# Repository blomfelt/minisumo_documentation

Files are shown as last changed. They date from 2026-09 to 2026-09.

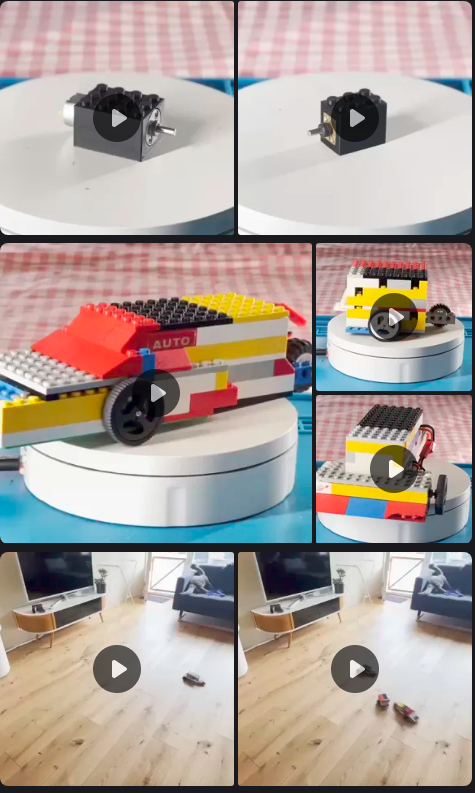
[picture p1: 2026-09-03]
img/lego concept från john till pg via discord 260510.png

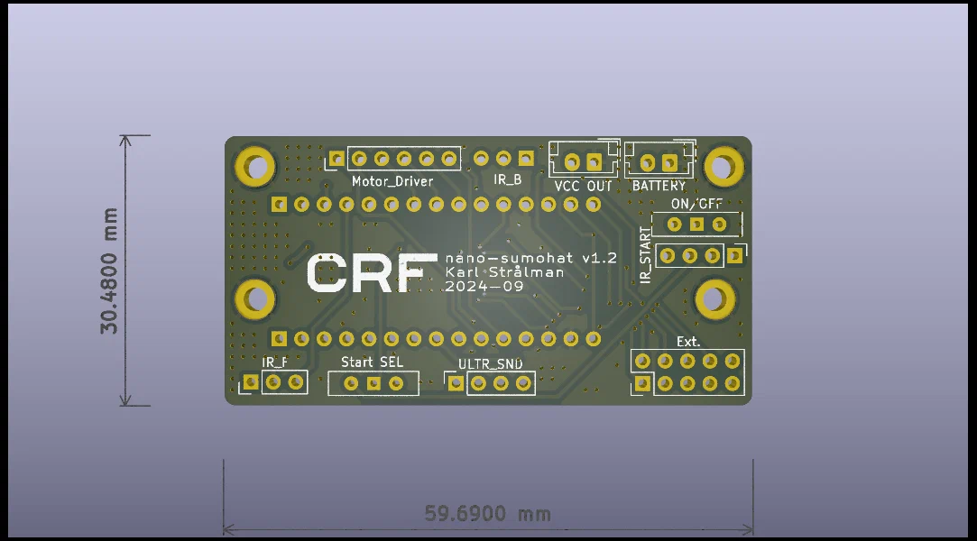
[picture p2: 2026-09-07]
documentation/resources/_gen/images/images/pcb_hu_88633c255bfc3661.webp

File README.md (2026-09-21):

# CRF minisumo++2027 (CRFminisumoplusplus2027)

A follow-up to the [CRF SumoBot](https://github.com/ChalmersRobotics/CRF-SumoBot)[^1] designed primarily by Kalle Strålman and David Strålman.

After RobotSM 2026 we sold out of kits that were arduino based and ran out of batteries that were cheap. While doing these changes we also chose to update the PCB and make some pretty big changes to the model, so why not make upgrades!?

## Concept for minisumo++2027
A minisumo .. plus some other things .. plus even some more!
- Minisumo for robotSM primarily, but as possible a module that can be a spring board into other things
- Minisumo that one steers like an RC car via bluetooth!
- Lego version! .. encapsulate motors and such into a robot combat like (or autonomous robot?) that can be lego'd together!
- [Death racers](https://www.youtube.com/watch?v=i10rxmsKHts)
- Robot combat base module
- More? Why not?? Probably possible
  - Line following!?
  - Esphome controlled robot w/ or w/o home assistant!?

## Goals and features
1. Good for beginners to meet the primary goal of minisumo for robotSM
2. Cheap as chips
3. Possibility to make really really smallish, for example to encapsulate into lego!
4. More voltage to motors!
5. Battery charging possible since using the c6!
6. Possibility to expand and reuse gpio's or other purpose robots!

## TODO
- [x] Choose wires or PCB for connection (PCB right now)
- [x] Add sensors
- [x] Add Sumo-code
- [x] Add bluetooth code
- [x] Control motors via bluetooth
- [ ] Design the chassis
- [ ] Write build instructions
- [ ] PCBs - need to build to confirm eg ALL footprints (all done by hand) && perform functional tests with everything mounted as designed with software running && confirm within eventual 3d packaging.

## Instructions
- Obtain Components and Chassis (See *Bill of Materials below*) or via a kit @ CRF while supplies last!
- Download the `minisumo-bot.ino` file from [releases on the right side](https://github.com/ChalmersRobotics/minisumoplusplus2027/releases)
- Build the robot according to the [instructions](TODO)
- Upload the code to the robot as in the [instructions](TODO) or as documented below.

### Instructions for pcb assembly / soldering incl tips and tricks
tbd

### Instructions for final assembly
tbd

### Instructions for uploading code to the ESP32
- Install Arduino IDE v2 from their [website](https://docs.arduino.cc/software/ide-v2/tutorials/getting-started/ide-v2-downloading-and-installing/)[^2] or your favourite package manager. Current version is 2.3.10.
- Install the required boards from the Boards Manager in the left column, second icon from the top:
    - esp32 by Espressif Systems (current version 3.3.11)
- Install the required libraries from the Library Manager, icon under the Boards Manager (or via Tools > Manage Libraries):
    - "NimBLE_Arduino" by h2zero (current version 2.5.1)
    - "HCSR04" by Martin Sosic (current version 2.0.0)
- Choose the correct board from the Select Board dropdown > Select other board and port. Then Search for *MakerGO ESP32 C6 SuperMini*. It will look as if nothing happens but that is fine.
- Connect the ESP32 to your computer while holding the BOOT button on the board. It will show up in the right column as something like `/dev/usb/ttyASM0` if you are on linux. Click Ok.
    - The board may not show up, in which case you need to hold the Boot button while connecting the board, then tapping the RST button and finally releasing the BOOT button.
- Paste the contents of `minisumo-bot.ino` into the default sketch or download the file and open it from File > Open
- Verify and/or Upload the sketch to the ESP32 using the checkbox and/or arrow in the top left corner.

### Bill of Materials
See [the google sheets bom](https://docs.google.com/spreadsheets/d/1KNLTKy2cLUtDrH-E30Gfz_4ahhQaqS2SGsFHG1Fw9_M/edit?usp=sharing))
- PCB
- 3D printed chassis
- [ESP32 C6 Super Mini](https://mischianti.org/esp32-c6-supermini-high-resolution-pinout-datasheet-schema-and-specs/)
- Battery 3.7v cr123 with recharge usb c contact built in!
- Battery contacts!
- Buck boost to push motor driver to 9v!
- Switch on / off .. a smaller one is needed
- Motor driver: L298N
- Ultrasonic sensor: HC-SR04
- IR sensor: v183
- Start module
- Cables

## Changelog

| Version | Changes |
| --- | --- |
| v1.0 | First draft |

## References
[^1]: CRF SumoBot, Kalle Strålman, [https://github.com/ChalmersRobotics/CRF-SumoBot](https://github.com/ChalmersRobotics/CRF-SumoBot)
[^2]: Downloading and installing the Arduino IDE 2, Arduino, [https://docs.arduino.cc/software/ide-v2/tutorials/getting-started/ide-v2-downloading-and-installing/](https://docs.arduino.cc/software/ide-v2/tutorials/getting-started/ide-v2-downloading-and-installing/)

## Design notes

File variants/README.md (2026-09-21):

The home of every variant of the minisumoplusplus bot. 

Each variant get their own folder, which contain both the code and any neccessary 3d-printing files.

Symlinks to other folders are permitted, if they for example use the same chassis as another bot.
A symlink is created in linux / WSL using the `ln -s source_file symbolic_link` command.

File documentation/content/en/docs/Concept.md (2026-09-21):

---
weight: 1
title: "Concept"
description: ""
icon: "article"
date: "2026-09-21T15:22:42+02:00"
lastmod: "2026-09-21T15:22:42+02:00"
draft: false
toc: true
---

A follow-up to the [CRF SumoBot](https://github.com/ChalmersRobotics/CRF-SumoBot)[^1] designed primarily by Kalle Strålman and David Strålman.

After RobotSM 2026 we sold out of kits that were arduino based and ran out of batteries that were cheap. While doing these changes we also chose to update the PCB and make some pretty big changes to the model, so why not make upgrades!?

## Concept for minisumo++2027
A minisumo .. plus some other things .. plus even some more!
- Minisumo for robotSM primarily, but as possible a module that can be a spring board into other things
- Minisumo that one steers like an RC car via bluetooth!
- Lego version! .. encapsulate motors and such into a robot combat like (or autonomous robot?) that can be lego'd together!
- [Death racers](https://www.youtube.com/watch?v=i10rxmsKHts)
- Robot combat base module
- More? Why not?? Probably possible
  - Line following!?
  - Esphome controlled robot w/ or w/o home assistant!?

## Goals and features
1. Good for beginners to meet the primary goal of minisumo for robotSM
2. Cheap as chips
3. Possibility to make really really smallish, for example to encapsulate into lego!
4. More voltage to motors!
5. Battery charging possible since using the c6!
6. Possibility to expand and reuse gpio's or other purpose robots!

## Variants
A minisumo .. plus some other things .. plus even some more!

- [Minisumo for robotSM](https://www.robotsm.se/competitions-and-rules/#:~:text=Sumo,-In) primarily, but as possible a module that can be a spring board into other things
- Minisumo that one steers like an RC car via bluetooth!
- Lego version! .. encapsulate motors and such into a robot combat like (or autonomous robot?) that can be lego'd together!
- Death racers: [video example](https://www.youtube.com/watch?v=i10rxmsKHts) and [official page](https://rockymountainreprapfestival.com/competitions/)
- [Robot combat](https://www.robotsm.se/competitions-and-rules/#:~:text=Robot%20combat) base module
- More? Why not?? Probably possible
    - [Line following](https://www.robotsm.se/competitions-and-rules/#:~:text=Line%20following)!?
    - Esphome controlled robot w/ or w/o home assistant!?

## References
[^1]: CRF SumoBot, Kalle Strålman, [https://github.com/ChalmersRobotics/CRF-SumoBot](https://github.com/ChalmersRobotics/CRF-SumoBot)

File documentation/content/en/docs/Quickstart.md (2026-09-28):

---
weight: 2
title: "Quickstart (minisumo)"
description: ""
icon: "star"
date: "2026-09-01T21:43:11+02:00"
lastmod: "2026-09-01T21:43:11+02:00"
draft: false
toc: true
---

Det finns även svensk version av instruktionerna, du kan byta språk längst upp till höger under **EN**, eller genom att [klicka här](/minisumo_documentation/sv/docs/).

- Obtain Components and Chassis (See [Bill of Materials](/docs/step_by_step/bom.md)) by buying a kit from us at CRF or by providing your own.
- Download the `minisumo-bot.ino` file from [the minisumo-bot folder on github](https://github.com/ChalmersRobotics/minisumoplusplus2027/blob/main/variants/minisumo-bot/minisumo-bot.ino)
- Build the robot according to the [instructions](/docs/step_by_step/)
- Upload the code to the robot as [described here](/docs/step_by_step/programming/).

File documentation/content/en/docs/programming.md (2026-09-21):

---
weight: 200
title: "Programming an ESP32"
description: ""
icon: "upload"
date: "2026-09-01T21:49:12+02:00"
lastmod: "2026-09-01T21:49:12+02:00"
draft: false
toc: true
---

- Install Arduino IDE v2 from their [website](https://docs.arduino.cc/software/ide-v2/tutorials/getting-started/ide-v2-downloading-and-installing/)[^3] or your favourite package manager. Current version is 2.3.8.
- Install the required boards from the Boards Manager in the left column, second icon from the top:
    - esp32 by Espressif Systems (current version 3.3.11)
- Install the required libraries from the Library Manager, icon under the Boards Manager (or via Tools > Manage Libraries):
    - "HCSR04" by Martin Sosic (current version 2.0.0)
    - If you are going to remote control it using bluetooth: "NimBLE_Arduino" by h2zero (current version 2.5.1)
- Choose the correct board from the Select Board dropdown > Select other board and port. Then Search for *MakerGO ESP32 C6 SuperMini*. It will look as if nothing happens but that is fine.
- Connect the ESP32 to your computer while holding the BOOT button on the board. It will show up in the right column as something like `/dev/usb/ttyASM0` if you are on linux. Click Ok.
    - The board may not show up, in which case you need to hold the Boot button while connecting the board, then tapping the RST button and finally releasing the BOOT button.
- Paste the contents of `minisumo-bot.ino` into the default sketch or download the file and open it from File > Open
- If you want to see the serial monitor when the ESP is connected to your computer you need to enable "*USB CDC On Boot*" under Tools in the top bar, after which you can open the Serial Monitor in the top right corner under the magnifying glass.
- Verify and/or Upload the sketch to the ESP32 using the checkbox and/or arrow in the top left corner.
- **Done!** Now it will run the code you uploaded to it every time it is powered on!

[^3]: Downloading and installing the Arduino IDE 2, Arduino, [https://docs.arduino.cc/software/ide-v2/tutorials/getting-started/ide-v2-downloading-and-installing/](https://docs.arduino.cc/software/ide-v2/tutorials/getting-started/ide-v2-downloading-and-installing/)

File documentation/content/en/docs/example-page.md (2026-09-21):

---
weight: 999
title: "CRF Minisumo bot"
description: ""
icon: "info"
date: "2026-09-01T19:05:21+02:00"
lastmod: "2026-09-01T19:05:21+02:00"
draft: true
toc: true
---

A follow-up to the [CRF SumoBot](https://github.com/ChalmersRobotics/CRF-SumoBot)[^1] designed by Kalle Strålman.

Bluetooth remote control code from Shib Sankar Das's [ESP32-Bluetooth-RC-Car-Project](https://github.com/Shib-Sankar-Das/ESP32-Bluetooth-RC-Car-Project/)[^2]

Please find:
- [Instructions and workshop intro (v1.2, updated 251105) - here](TODO)
- [3D manufacturing files](TODO)
- [complete release package - here!](https://github.com/ChalmersRobotics/CRF-SumoBot/releases)

"Rendered image of nano-hat v1.2"

## TODO
- [x] Choose wires or PCB for connection (PCB right now)
- [x] Add sensors
- [x] Add Sumo-code
- [ ] Design the chassis
- [ ] Write build instructions

## Instructions
- Obtain Components and Chassis (See *Bill of Materials below*)
- Download the `minisumo-bot.ino` file from [releases on the right side](https://github.com/ChalmersRobotics/CRF-SumoBot/releases)
- Build the robot according to the [instructions](TODO)
- Upload the code to the robot as in the [instructions](TODO) or as documented below.

## Uploading code to the ESP32
- Install Arduino IDE v2 from their [website](https://docs.arduino.cc/software/ide-v2/tutorials/getting-started/ide-v2-downloading-and-installing/)[^3] or your favourite package manager. Current version is 2.3.8.
- Install the required boards from the Boards Manager in the left column, second icon from the top:
    - esp32 by Espressif Systems (current version 3.3.11)
- Install the required libraries from the Library Manager, icon under the Boards Manager (or via Tools > Manage Libraries):
    - "NimBLE_Arduino" by h2zero (current version 2.5.1)
    - "HCSR04" by Martin Sosic (current version 2.0.0)
- Choose the correct board from the Select Board dropdown > Select other board and port. Then Search for *MakerGO ESP32 C6 SuperMini*. It will look as if nothing happens but that is fine.
- Connect the ESP32 to your computer while holding the BOOT button on the board. It will show up in the right column as something like `/dev/usb/ttyASM0` if you are on linux. Click Ok.
    - The board may not show up, in which case you need to hold the Boot button while connecting the board, then tapping the RST button and finally releasing the BOOT button.
- Paste the contents of `minisumo-bot.ino` into the default sketch or download the file and open it from File > Open
- Verify and/or Upload the sketch to the ESP32 using the checkbox and/or arrow in the top left corner.

## Bill of Materials
- PCB
- 3D printed chassis
- ESP32 C6 Supermini
- Motor driver: L298N
- Ultrasonic sensor: HC-SR04
- IR sensor: v183
- Cables

## Changelog

| Version | Changes |
| --- | --- |
| v1.0 | First draft |

## References
[^1]: CRF SumoBot, Kalle Strålman, [https://github.com/ChalmersRobotics/CRF-SumoBot](https://github.com/ChalmersRobotics/CRF-SumoBot)
[^2]: ESP32-Bluetooth-RC-Car-Project, Shib Sankar Das, [https://github.com/Shib-Sankar-Das/ESP32-Bluetooth-RC-Car-Project/](https://github.com/Shib-SankAar-Das/ESP32-Bluetooth-RC-Car-Project/)
[^3]: Downloading and installing the Arduino IDE 2, Arduino, [https://docs.arduino.cc/software/ide-v2/tutorials/getting-started/ide-v2-downloading-and-installing/](https://docs.arduino.cc/software/ide-v2/tutorials/getting-started/ide-v2-downloading-and-installing/)

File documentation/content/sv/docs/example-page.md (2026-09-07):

---
weight: 2
title: "CRF Minisumo bot"
description: ""
icon: "article"
date: "2026-09-01T19:05:21+02:00"
lastmod: "2026-09-01T19:05:21+02:00"
draft: false
toc: true
---

A follow-up to the [CRF SumoBot](https://github.com/ChalmersRobotics/CRF-SumoBot)[^1] designed by Kalle Strålman.

Bluetooth remote control code from Shib Sankar Das's [ESP32-Bluetooth-RC-Car-Project](https://github.com/Shib-Sankar-Das/ESP32-Bluetooth-RC-Car-Project/)[^2]

Please find:
- [Instructions and workshop intro (v1.2, updated 251105) - here](TODO)
- [3D manufacturing files](TODO)
- [complete release package - here!](https://github.com/ChalmersRobotics/CRF-SumoBot/releases)

"Rendered image of nano-hat v1.2"

## TODO
- [x] Choose wires or PCB for connection (PCB right now)
- [x] Add sensors
- [x] Add Sumo-code
- [ ] Design the chassis
- [ ] Write build instructions

## Instructions
- Obtain Components and Chassis (See *Bill of Materials below*)
- Download the `minisumo-bot.ino` file from [releases on the right side](https://github.com/ChalmersRobotics/CRF-SumoBot/releases)
- Build the robot according to the [instructions](TODO)
- Upload the code to the robot as in the [instructions](TODO) or as documented below.

## Uploading code to the ESP32
- Install Arduino IDE v2 from their [website](https://docs.arduino.cc/software/ide-v2/tutorials/getting-started/ide-v2-downloading-and-installing/)[^3] or your favourite package manager. Current version is 2.3.8.
- Install the required boards from the Boards Manager in the left column, second icon from the top:
    - esp32 by Espressif Systems (current version 3.3.11)
- Install the required libraries from the Library Manager, icon under the Boards Manager (or via Tools > Manage Libraries):
    - "NimBLE_Arduino" by h2zero (current version 2.5.1)
    - "HCSR04" by Martin Sosic (current version 2.0.0)
- Choose the correct board from the Select Board dropdown > Select other board and port. Then Search for *MakerGO ESP32 C6 SuperMini*. It will look as if nothing happens but that is fine.
- Connect the ESP32 to your computer while holding the BOOT button on the board. It will show up in the right column as something like `/dev/usb/ttyASM0` if you are on linux. Click Ok.
    - The board may not show up, in which case you need to hold the Boot button while connecting the board, then tapping the RST button and finally releasing the BOOT button.
- Paste the contents of `minisumo-bot.ino` into the default sketch or download the file and open it from File > Open
- Verify and/or Upload the sketch to the ESP32 using the checkbox and/or arrow in the top left corner.

## Bill of Materials
- PCB
- 3D printed chassis
- ESP32 C6 Supermini
- Motor driver: L298N
- Ultrasonic sensor: HC-SR04
- IR sensor: v183
- Cables

## Changelog

| Version | Changes |
| --- | --- |
| v2.0 | <ul><li>Updated PCB design</li><li>Changed to ESP from Arduino</li></ul> |
| v1.2 | <ul><li>Add EN_A and EN_B pins for controlling H-Bridge speed</li><li>Move start module placement slightly more towards the edge</li><li>Add header pins for unused ports on the Arduino to allow further extension / mods</li>Add an optional switch to pull-up and bypass start module</ul> |
| v1.1 | <ul><li>Move mounting holes slightly</li><li>Add header pins for start module</li></ul> |
| v1.0 | First draft |

## References
[^1]: CRF SumoBot, Kalle Strålman, [https://github.com/ChalmersRobotics/CRF-SumoBot](https://github.com/ChalmersRobotics/CRF-SumoBot)
[^2]: ESP32-Bluetooth-RC-Car-Project, Shib Sankar Das, [https://github.com/Shib-Sankar-Das/ESP32-Bluetooth-RC-Car-Project/](https://github.com/Shib-SankAar-Das/ESP32-Bluetooth-RC-Car-Project/)
[^3]: Downloading and installing the Arduino IDE 2, Arduino, [https://docs.arduino.cc/software/ide-v2/tutorials/getting-started/ide-v2-downloading-and-installing/](https://docs.arduino.cc/software/ide-v2/tutorials/getting-started/ide-v2-downloading-and-installing/)

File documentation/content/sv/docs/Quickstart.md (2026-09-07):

---
weight: 1
title: "Quickstart"
description: ""
icon: "article"
date: "2026-09-01T21:43:11+02:00"
lastmod: "2026-09-01T21:43:11+02:00"
draft: false
toc: true
---

- Obtain Components and Chassis (See [Bill of Materials](/docs/step_by_step/bom.md))
- Download the `minisumo-bot.ino` file from [releases on the right side](https://github.com/ChalmersRobotics/CRF-SumoBot/releases)
- Build the robot according to the [instructions](TODO)
- Upload the code to the robot as in the [instructions](TODO) or as [described here](/docs/step_by_step/programming/).

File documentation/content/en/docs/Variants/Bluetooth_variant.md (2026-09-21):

---
weight: 12
title: "Bluetooth"
description: ""
icon: "article"
date: "2026-09-21T14:24:28+02:00"
lastmod: "2026-09-21T14:24:28+02:00"
draft: false
toc: true
---

The bluetooth variant of the sumobot uses Bluetooth Low Energy (BLE) to communicate with for example an app on your phone. 

If you are using android you can use the app [BLE Joystick](https://play.google.com/store/apps/details?id=iyok.com.blejoystickpro) to control the robot.

For debugging the characteristics you can use the app [nRF Connect](https://play.google.com/store/apps/details?id=no.nordicsemi.android.mcp).

For this bot there are not complete build instructions, but the info found in the [quickstart guide for the minisumo bot](/docs/quickstart) and the [full build instructions for the minisumo bot]() applies, except that you don't need the IR sensors or Ultrasonic distance sensors, however you can add them to the bot and modify the code to include them if you want!

The code is located at [variants/Bluetooth_control/Bluetooth_control.ino](https://github.com/ChalmersRobotics/minisumoplusplus2027/blob/main/variants/Bluetooth_control/Bluetooth_control.ino) in the GitHub.

The 3D-printing files are located at [this link](link)

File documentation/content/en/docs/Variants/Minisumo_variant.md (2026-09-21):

---
weight: 11
title: "Minisumo"
description: ""
icon: "article"
date: "2026-09-21T14:24:43+02:00"
lastmod: "2026-09-21T14:24:43+02:00"
draft: false
toc: true
---

The standard version of the bot.

The kit which we sell at CRF contains everything you need to build this robot, after which it will be ready to use in the Minisumo competition during RobotSM. 

For full build instructions see [this link]()

See also the [quickstart guide for the minisumo bot](/docs/quickstart)

The code is located at [https://github.com/ChalmersRobotics/minisumoplusplus2027/blob/main/variants/minisumo-bot/minisumo-bot.ino](https://github.com/ChalmersRobotics/minisumoplusplus2027/blob/main/variants/minisumo-bot/minisumo-bot.ino)

The 3D-printing files are located at [this link](link)

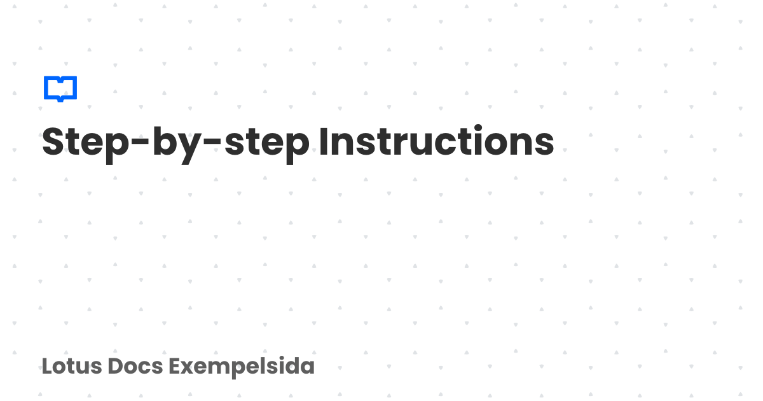
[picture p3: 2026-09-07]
documentation/resources/_gen/images/opengraph/card-base-2_hu_d1e118c8bb8d81ea.png

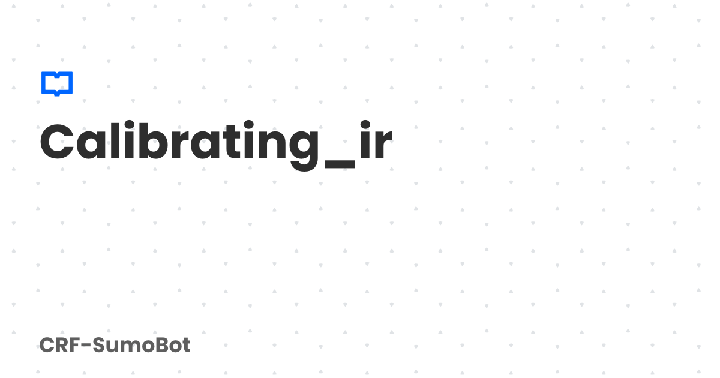
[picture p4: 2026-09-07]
documentation/resources/_gen/images/opengraph/card-base-2_hu_2ad661b17c352fed.png

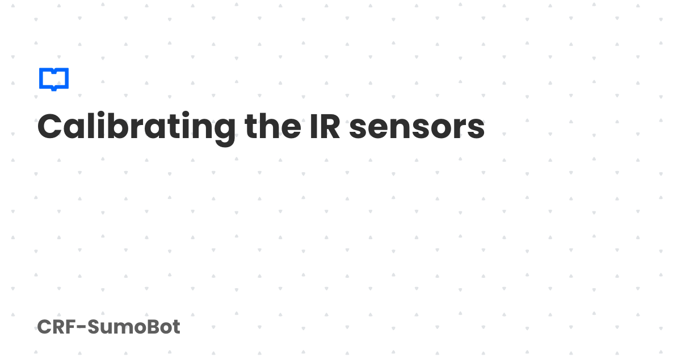
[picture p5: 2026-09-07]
documentation/resources/_gen/images/opengraph/card-base-2_hu_c7da4d8de7d2e4bb.png

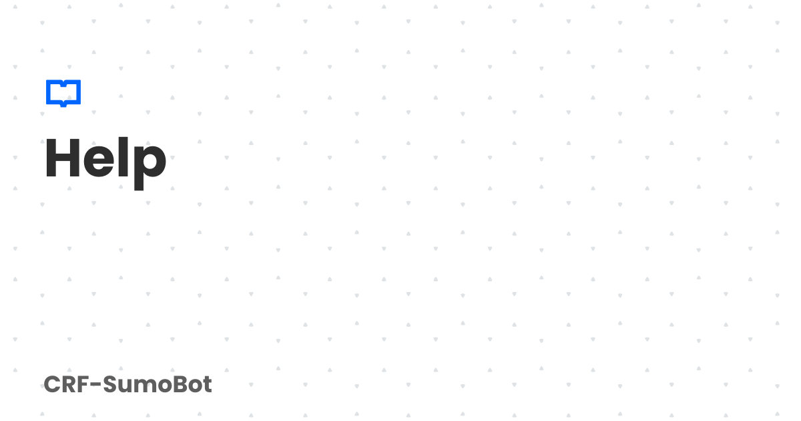
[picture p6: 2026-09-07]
documentation/resources/_gen/images/opengraph/card-base-2_hu_98e0b63b263da06a.png

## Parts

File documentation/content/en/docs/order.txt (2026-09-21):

1   Concept
1   Quickstart
2   example-page (CRF Minisumo bot)
3   Step-by-step instructions
10  Bill of materials
20  Soldering
30  Calibrating IR sensors
40  Programming
100 Variants
120 Bluetooth variant
998 Contributing
999 Changelog
999 Help

Layout:
1.  Concept, goals and features
2.  Quickstart for Minisumo version
3.  Minisumo variant step-by-step build instructions
10. Variants (list with link to each page? Fold-out folder with a page for each variant?)
    11. Minisumo Variant
        - Quickstart (link to the code)
        - Bill of Materials
    12. Bluetooth Variant
        - Quickstart (link to the code)
        - Bill of Materials
    13. LEGO variant
    14. Linefollower variant
    15. Death Racer variant
    16. Combat robot variant

100. Soldering

200. Programming

300. Calibrating the IR Sensors

997 Contributing
998 Changelog
999 Help

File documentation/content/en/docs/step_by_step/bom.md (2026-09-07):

---
weight: 10
title: "Bill of Materials"
description: ""
icon: "article"
date: "2026-09-01T21:46:31+02:00"
lastmod: "2026-09-01T21:46:31+02:00"
draft: false
toc: true
---

The materials needed for the project is:
- PCB
- 3D printed chassis
- ESP32 C6 Supermini
- Motor driver: L298N
- Ultrasonic sensor: HC-SR04
- IR sensor: v183
- Cables

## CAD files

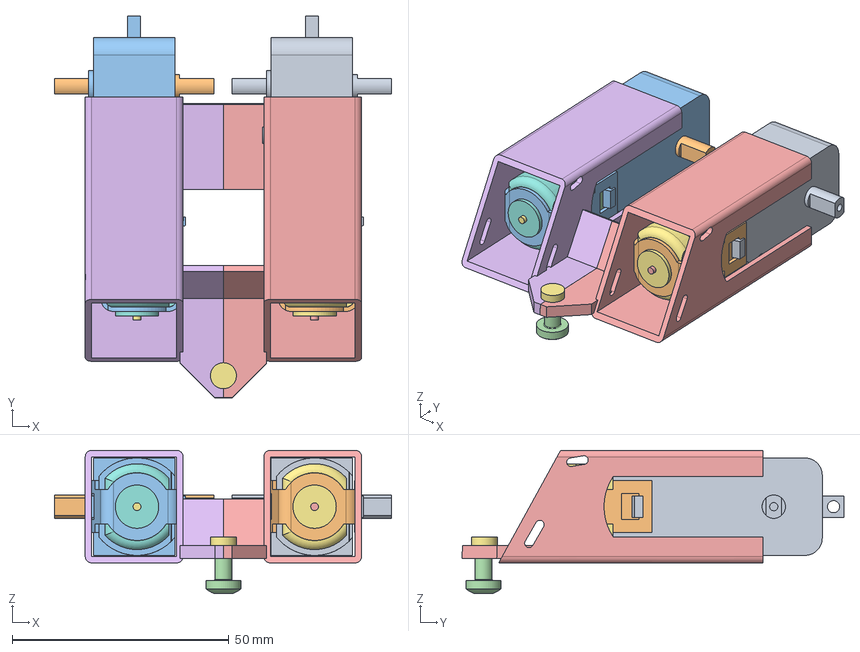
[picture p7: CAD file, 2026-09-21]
3d/linefollower-main_assy.FCStd
77.8 x 88.2 x 33.1 mm
Surface 1
Surface 001
Surface 002
M4x8-Screw
Thickness (Mirror #1)

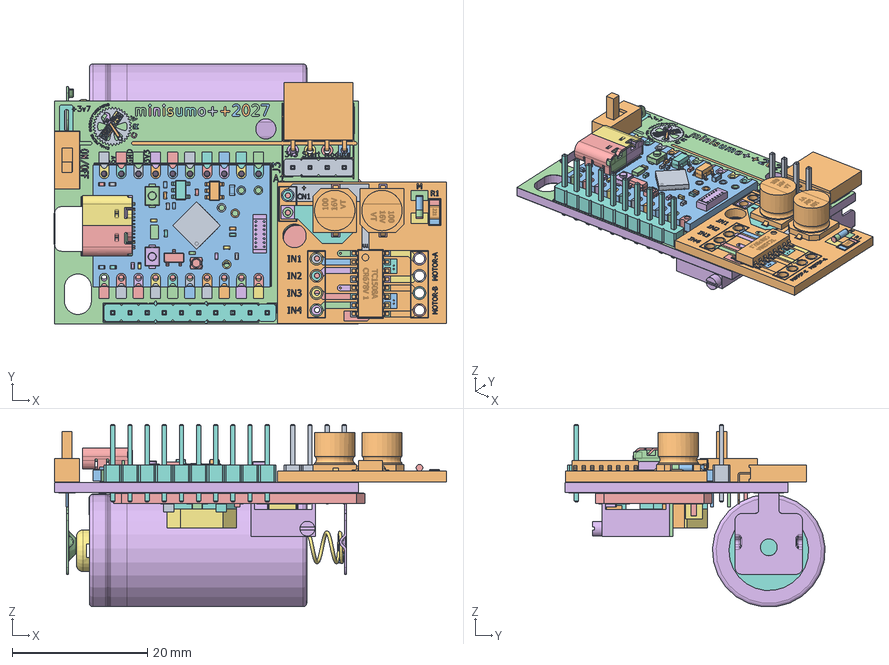
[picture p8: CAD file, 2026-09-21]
3d/PCB_assy.FCStd
58.0 x 38.5 x 27.0 mm
L298N_mini320
L298N_mini321
L298N_mini322
L298N_mini323
L298N_mini324
L298N_mini325
L298N_mini326
L298N_mini327
L298N_mini328
L298N_mini329
L298N_mini330
L298N_mini331
L298N_mini332
L298N_mini333
L298N_mini334
L298N_mini335
L298N_mini336
L298N_mini337
L298N_mini338
L298N_mini339
L298N_mini340
L298N_mini341
L298N_mini342
L298N_mini343
L298N_mini344
L298N_mini345
L298N_mini346
L298N_mini347
L298N_mini348
L298N_mini349
L298N_mini350
L298N_mini351
L298N_mini352
L298N_mini353
L298N_mini354
L298N_mini355
L298N_mini356
L298N_mini357
L298N_mini358
L298N_mini359
L298N_mini360
L298N_mini361
L298N_mini362
L298N_mini363
L298N_mini364
L298N_mini365
L298N_mini366
L298N_mini367
L298N_mini368
L298N_mini369
L298N_mini370
L298N_mini371
L298N_mini372
L298N_mini373
L298N_mini374
L298N_mini375
L298N_mini376
L298N_mini377
L298N_mini378
L298N_mini379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

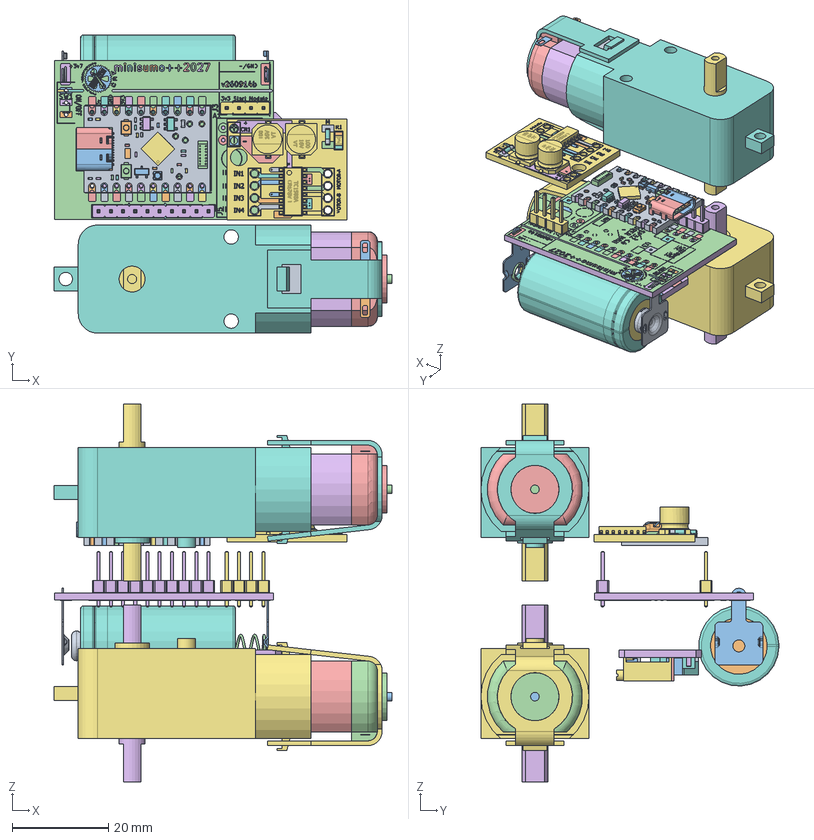
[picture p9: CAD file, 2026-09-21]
3d/main_assy_260914a.FCStd
70.2 x 62.0 x 78.6 mm
PCB
Corps
Corps001
Corps002
Corps003
Corps004
Corps005
Corps006
Corps007
Corps008
Corps009
C_0402_1005Metric
C_0402_1005Metric001
C_0402_1005Metric002
C_0402_1005Metric003
C_0402_1005Metric004
C_0402_1005Metric005
C_0402_1005Metric006
C_0402_1005Metric007
C_0402_1005Metric008
C_0402_1005Metric009
C_0402_1005Metric010
C_0402_1005Metric011
C_0402_1005Metric012
C_0603_1608Metric
Button_black_002
SOT-23-3
Button_black_003
io23
SOT_23_5_LTH7
io21
io22
io12
io13
LED_0402_1005Metric001
antenne
Corps010
Corps011
Corps012
Corps013
Corps014
Corps015
Corps016
Corps017
Corps018
Corps019
QFN_32_1EP_5x5mm_P05mm_EP33x33mm
SOT_23_5_Regul3.3
LED_0402_1005Metric
MicroCrystal_CC8V_T1A
LED_WS2812B-Mini_PLCC4_3.5x3.5mm_P1.8mm001
Corps002 (Mirror #1)
R_0402_1005Metric
R_0402_1005Metric001
R_0402_1005Metric002
R_0402_1005Metric003
R_0402_1005Metric004
USB_C_Receptacle_16P_TopMnt_Horizontal_GCT_USB4105-xx-A037
USB_C_Receptacle_16P_TopMnt_Horizontal_GCT_USB4105-xx-A038
USB_C_Receptacle_16P_TopMnt_Horizontal_GCT_USB4105-xx-A039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

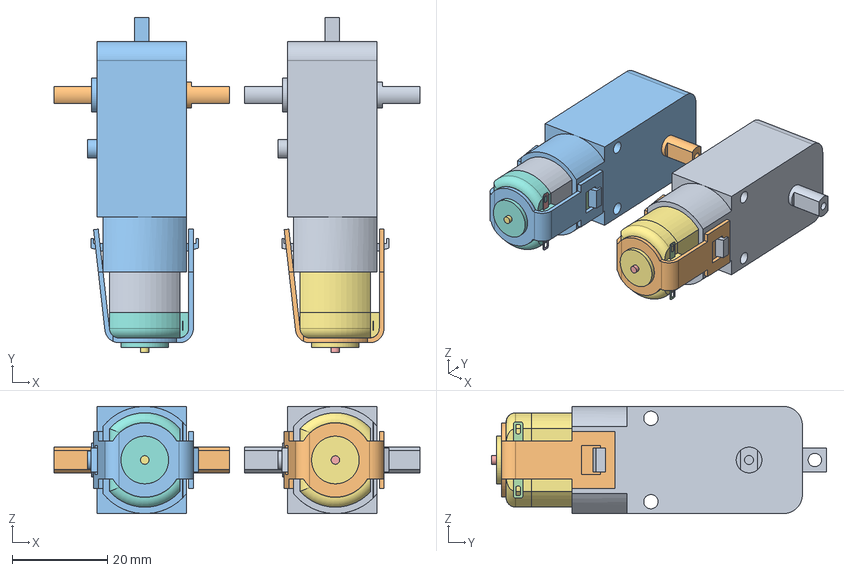
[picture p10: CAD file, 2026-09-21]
3d/main_assy.FCStd
76.8 x 70.2 x 22.5 mm
Surface 1
Surface 001
Surface 002

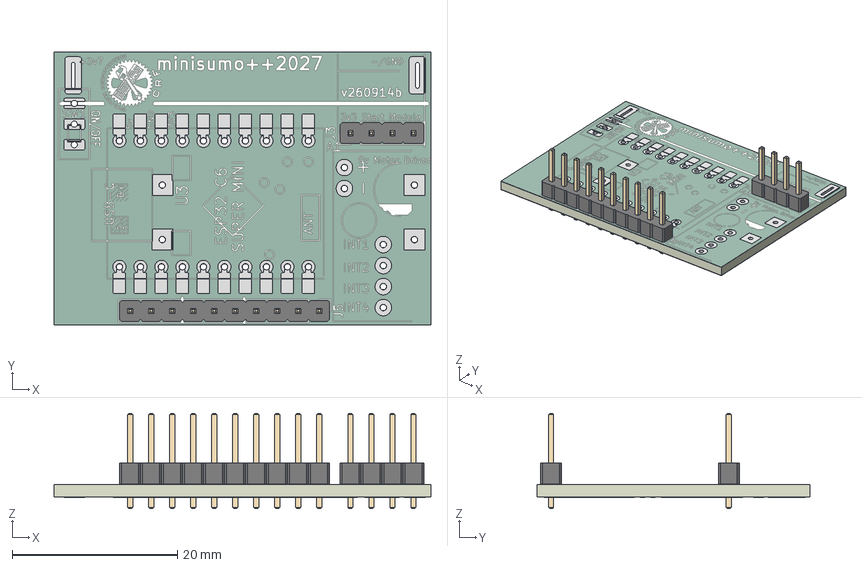
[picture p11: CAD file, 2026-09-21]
3d/steps/minisumo_plusplus_2027-260915a.step
45.6 x 33.0 x 11.5 mm
PinHeader_1x10_P254mm_Vertical
PinHeader_1x04_P254mm_Vertical
min62FE_copper
min62FE_pad
min62FE_via
min62FE_silkscreen x 2
min62FE_soldermask x 2
min62FE_PCB

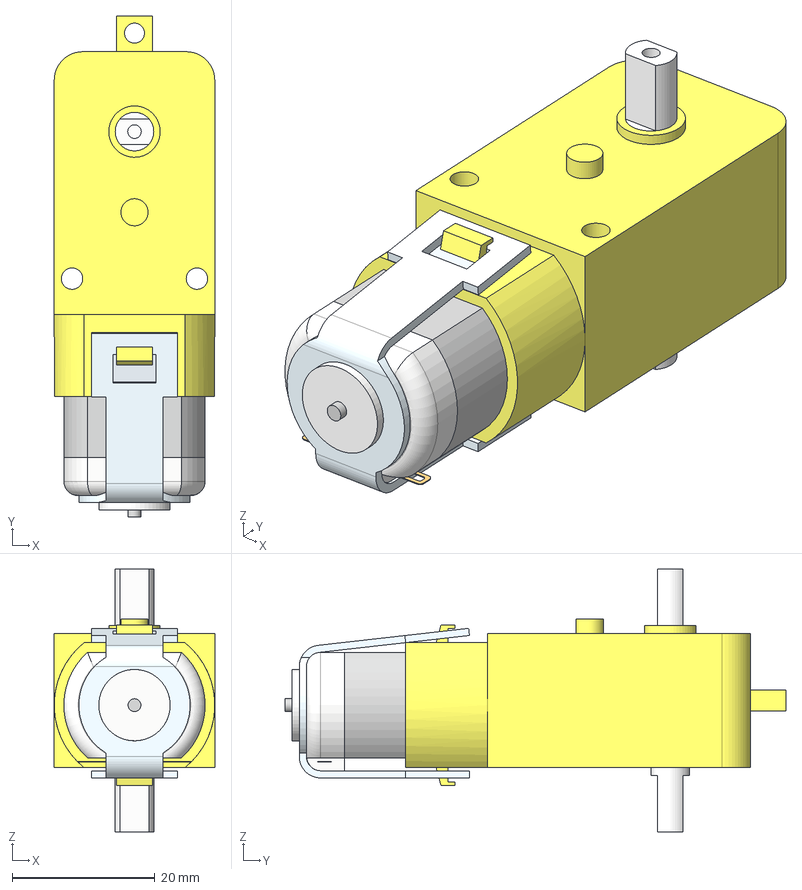
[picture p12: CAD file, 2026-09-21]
3d/steps/TT Motor Dual Shaft.step
22.5 x 70.2 x 36.8 mm
Surface 1

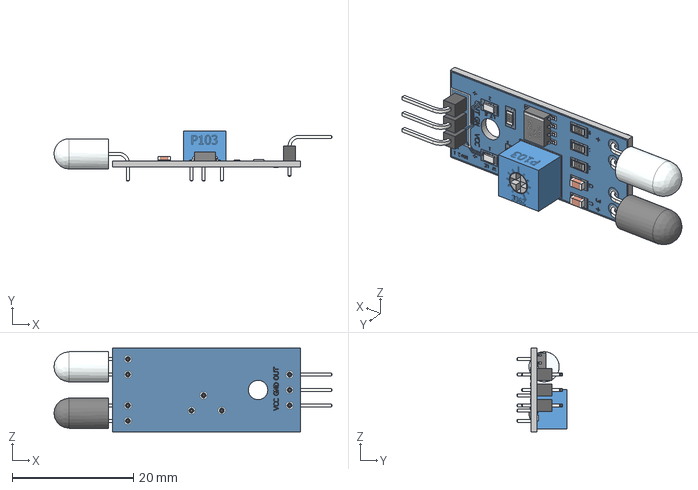
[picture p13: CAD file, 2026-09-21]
3d/steps/IR_LM393_pin.stp
45.9 x 8.31 x 13.8 mm

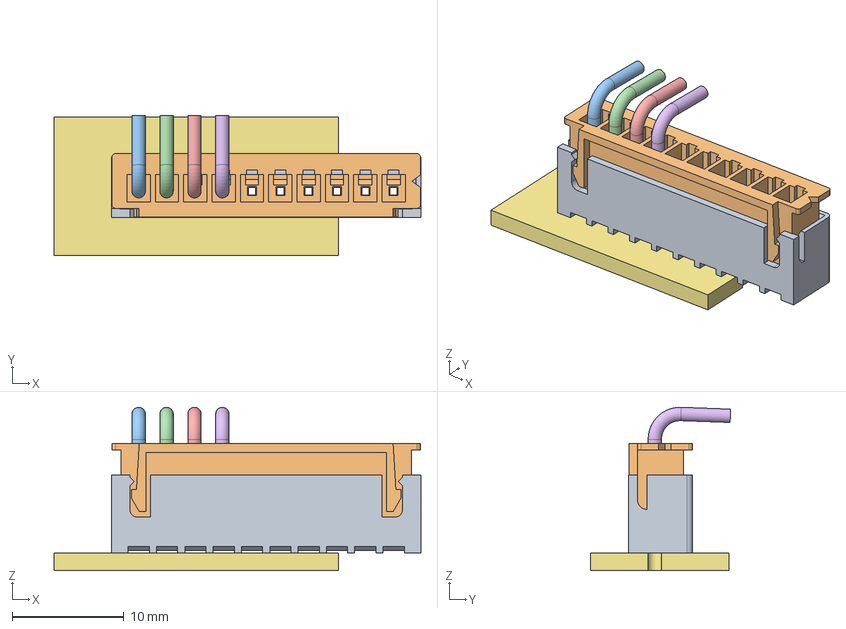
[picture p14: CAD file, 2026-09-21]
3d/XH_top_entry+housing-10pin_2.54mm.FCStd
32.9 x 12.6 x 14.6 mm
Top_entry_base x 2
Housing x 2
red_wire
blue_wire
black_wire
green_wire
PCB_example

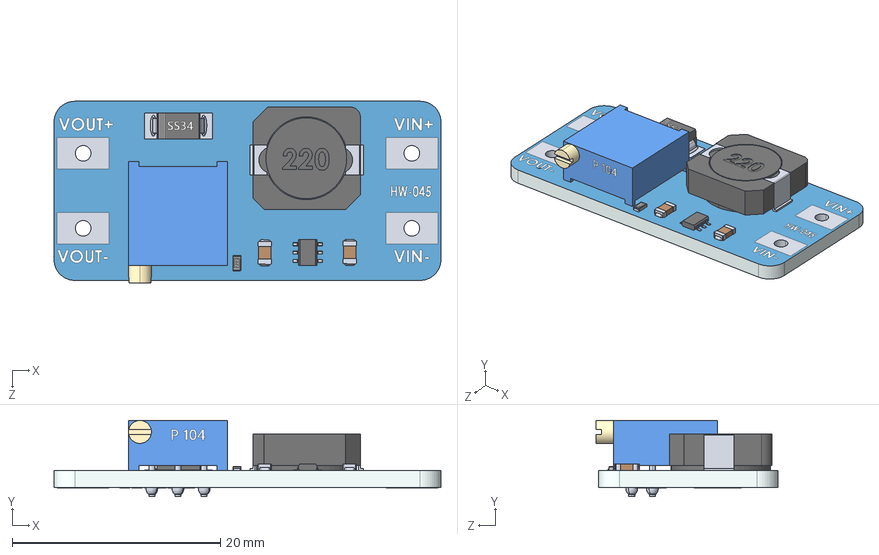
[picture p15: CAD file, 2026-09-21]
3d/steps/MT3608 Converter.STEP
37.1 x 7.30 x 17.4 mm
MT3608 Converter PCB
smdS537diode
tinySMDResistor222
smdceramiccapacitorbrown x 2
tinysmdChip6pin
HorizonatalTrimmerP104
solder x 3
smbInductor220

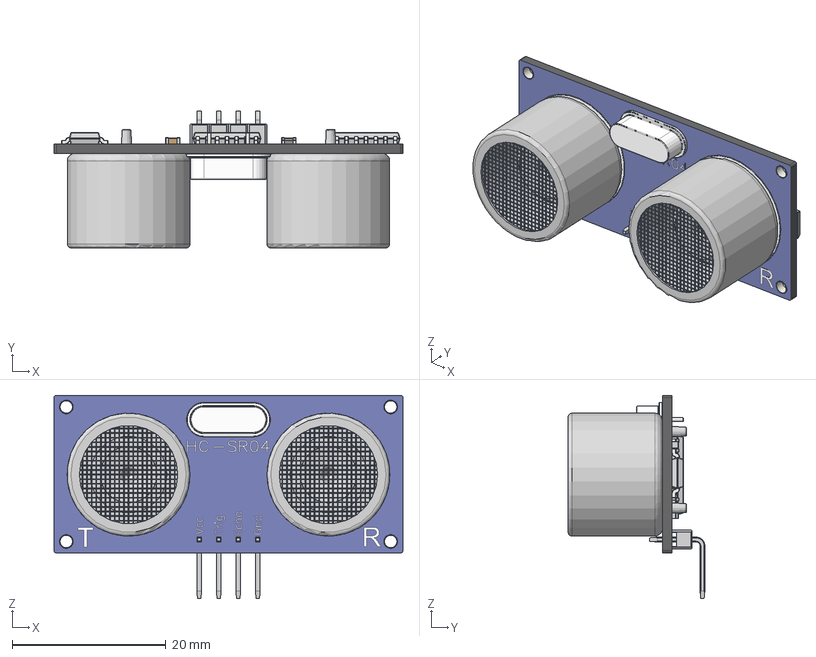
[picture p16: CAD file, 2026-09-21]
3d/steps/HC-SR04_UltraSonic Sensor.step
45.4 x 17.8 x 26.4 mm

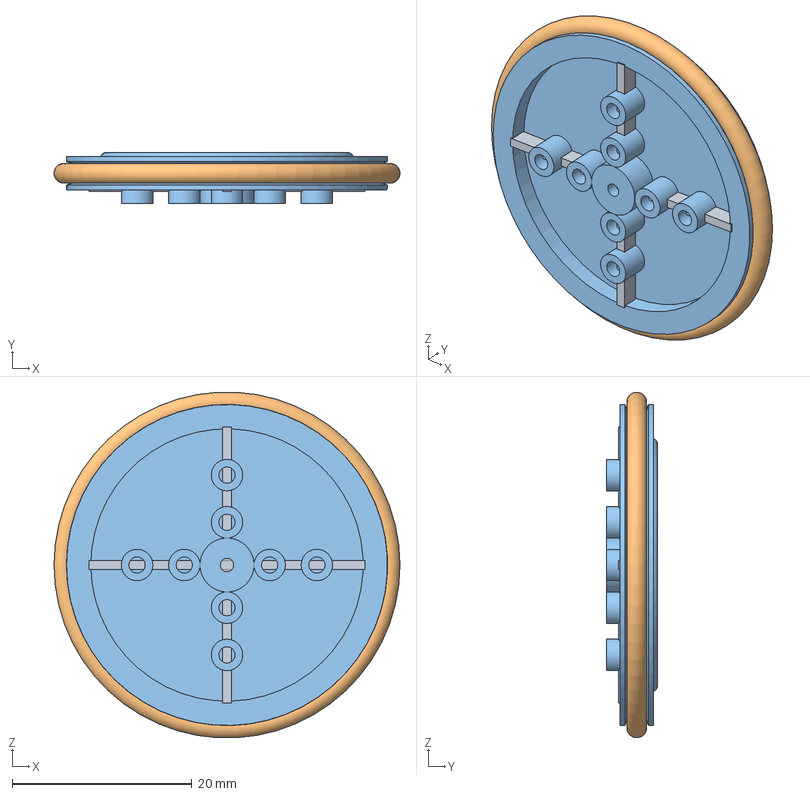
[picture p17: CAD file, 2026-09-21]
3d/wheel.FCStd
38.5 x 5.65 x 38.4 mm

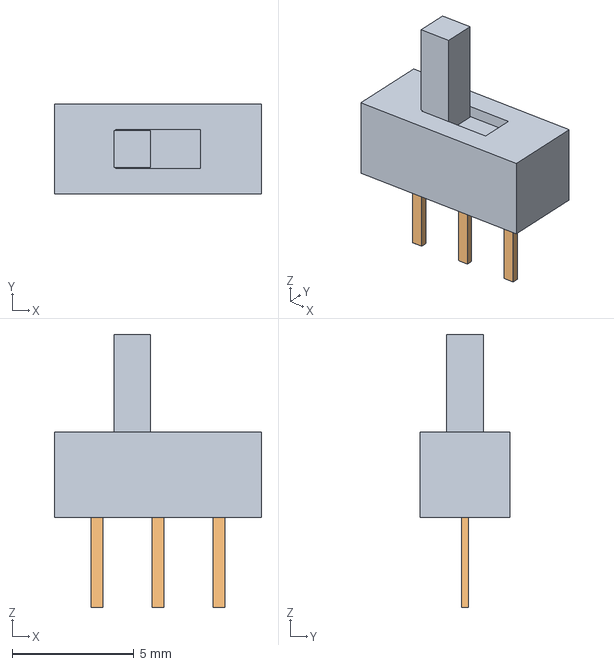
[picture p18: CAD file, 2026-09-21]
3d/steps/switch_slide_SPST_SS-12D00G4_1P2T.step
8.50 x 3.70 x 11.2 mm
pins

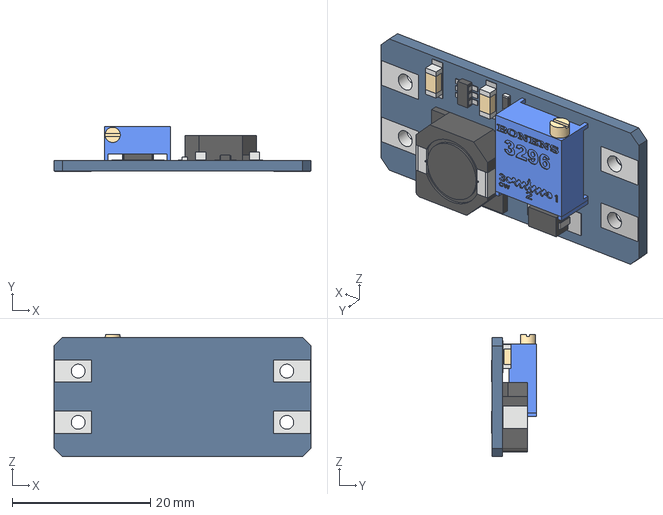
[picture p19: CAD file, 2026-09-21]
3d/steps/MT3608 v3.step
37.2 x 6.49 x 17.7 mm

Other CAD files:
3d/line_follower_assy.FCStd
3d/IR_sensor.FCStd
3d/ultrasonic_sensor_HC-sr04.FCStd
3d/steps/minisumo_plusplus_2027-proto0_ordered_260916b.step
3d/envelope.FCStd
3d/Old_Sumobot.v7.3mf
3d/XH_top_entry+housing.FCStd
3d/start_module.FCStd
3d/steps/Bat neg.STEP
3d/steps/Bat pos.STEP
3d/steps/CR123.step
3d/steps/L298N_mini.stp
3d/steps/LM2596-HW-411.stp
3d/steps/XL6009.STEP
3d/steps/minisumo_plusplus_2027-260914a pre design review.step
3d/steps/minisumo_plusplus_2027-260914b.step
3d/steps/minisumo_plusplus_2027-260916a.step
3d/steps/super_mini_esp32-c6_b.step
3d/switch_slide_SPST_SS-12D00G4_1P2T.FCStd

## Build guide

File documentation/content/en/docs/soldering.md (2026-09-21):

---
weight: 100
title: "Soldering"
description: ""
icon: "ink_pen"
date: "2026-09-02T16:56:09+02:00"
lastmod: "2026-09-02T16:56:09+02:00"
draft: false
toc: true
---

A quick guide on how to solder

## See also:
- [https://learn.sparkfun.com/tutorials/how-to-solder-through-hole-soldering/all#soldering-your-first-component](https://learn.sparkfun.com/tutorials/how-to-solder-through-hole-soldering/all#soldering-your-first-component)
- [https://www.instructables.com/How-to-solder/](https://www.instructables.com/How-to-solder/)
- [https://www.aaroncake.net/electronics/solder.htm](https://www.aaroncake.net/electronics/solder.htm)

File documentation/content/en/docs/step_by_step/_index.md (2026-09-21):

---
weight: 3
title: "Step-by-step Instructions"
description: ""
icon: "article"
date: "2026-09-01T21:46:07+02:00"
lastmod: "2026-09-01T21:46:07+02:00"
draft: false
toc: true
---

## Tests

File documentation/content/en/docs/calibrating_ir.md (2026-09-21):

---
weight: 300
title: "Calibrating the IR sensors"
description: ""
icon: "lightbulb_2"
date: "2026-09-01T22:09:18+02:00"
lastmod: "2026-09-01T22:09:18+02:00"
draft: false
toc: true
---

To make sure the robot can distinguish between the light and dark areas of the arena the IR sensors needs to be calibrated by turning the small screw on top of the blue box of the sensor. 

When the robot is placed on the edge of the arena, turn the screw until the light is turned on when the sensor is located over the white part of the arena and off when over the black area. Do the same procedure for both sensors.

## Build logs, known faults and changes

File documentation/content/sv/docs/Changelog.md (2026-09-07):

---
weight: 999
title: "Changelog"
description: ""
icon: "article"
date: "2026-09-01T21:50:35+02:00"
lastmod: "2026-09-01T21:50:35+02:00"
draft: false
toc: true
---
| Version | Changes |
| --- | --- |
| v2.0 | <ul><li>Updated PCB design</li><li>Changed to ESP from Arduino</li></ul> |
| v1.2 | <ul><li>Add EN_A and EN_B pins for controlling H-Bridge speed</li><li>Move start module placement slightly more towards the edge</li><li>Add header pins for unused ports on the Arduino to allow further extension / mods</li><li>Add an optional switch to pull-up and bypass start module</li></ul> |
| v1.1 | <ul><li>Move mounting holes slightly</li><li>Add header pins for start module</li></ul> |
| v1.0 | First draft |

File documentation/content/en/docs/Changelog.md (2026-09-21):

---
weight: 999
title: "Changelog"
description: ""
icon: "change_history"
date: "2026-09-01T21:50:35+02:00"
lastmod: "2026-09-01T21:50:35+02:00"
draft: false
toc: true
---
| Version | Changes |
| --- | --- |
| v1.0 | First draft |

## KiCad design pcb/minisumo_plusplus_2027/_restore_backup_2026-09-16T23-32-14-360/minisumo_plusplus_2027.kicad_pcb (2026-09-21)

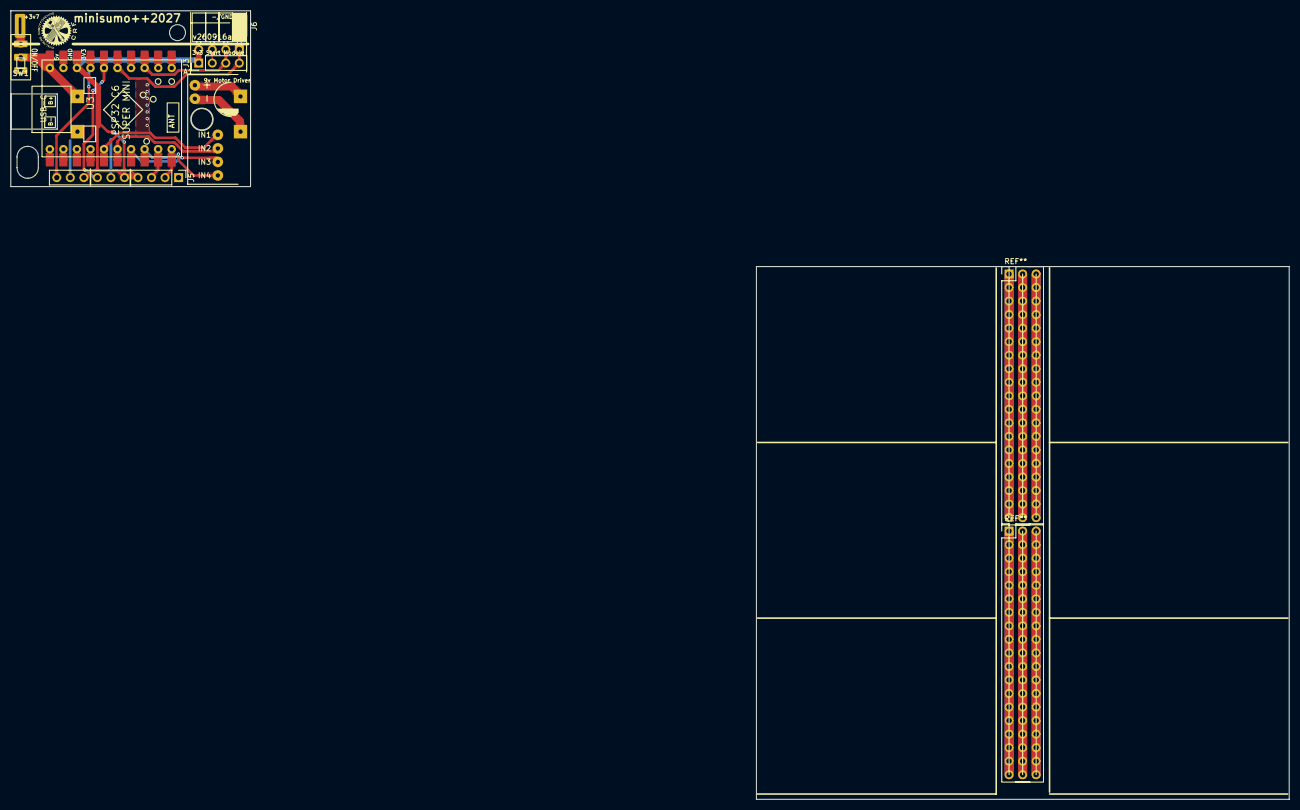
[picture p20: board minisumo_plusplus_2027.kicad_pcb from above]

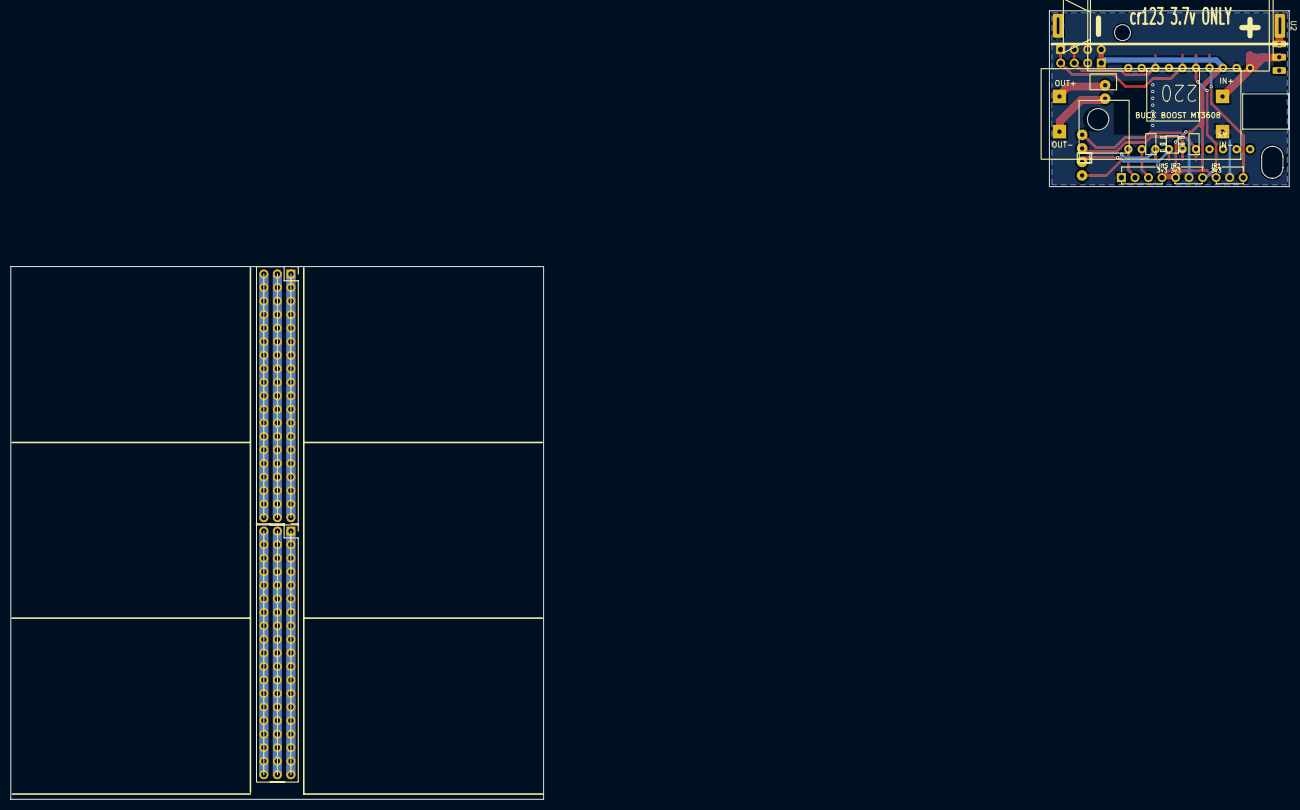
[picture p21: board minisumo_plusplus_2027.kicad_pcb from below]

Board: 2 copper layers, 45.0 x 33.0 mm, 8 parts (2 on the bottom side), 16 nets.

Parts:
A1: Mini_L298N_2_Channel_H_Bridge_DC_Motor_Driver_Board_with_MX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
A3: MT3608 DC-DC Boost Module – 28V 2A Step-Up Power Module
J3: Start Module - Conn_01x04_Pin; PinHeader_1x04_P2.54mm_Vertical
J5: Conn_01x10_Pin; PinHeader_1x10_P2.54mm_Vertical
J6: Start Module - Conn_01x04_Pin; PinSocket_1x04_P2.54mm_Horizontal
SW1: SW_SPDT; SPST_switch_SS-12D00G4_1P2T_2.5mm_pitch_vert
U2: battery cr123 3.7v with contacts for 18650
U3: ESP32-C6-SuperMini; ESP32-C6-SuperMini_SMD_THT

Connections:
3v3: J3.1, J5.4, J5.5, J5.8, J6.4, U3.3 (3v3)
/3v7 (>3v3 & <5v): A3.1 (IN+), SW1.2 (B), U3.1 (5V)
/9v: A1.1 (pwr), A3.3 (OUT+)
GND: A3.2 (IN-), J3.2, J5.1, J5.6, J5.9, J6.3, U2.2 (-/gnd), U3.2 (GND)
IR Front: J5.10, U3.4 (GPIO20)
IR Rear: J5.7, U3.5 (GPIO19)
unnamed: A1.3 (INT1), U3.15 (GPIO2-A2)
unnamed: A1.4 (INT2), U3.16 (GPIO3-A3)
unnamed: A1.5 (INT3), U3.17 (GPIO4-A4)
unnamed: A1.6 (INT4), U3.18 (GPIO5-A5)
unnamed: A1.2 (gnd), A3.4 (OUT-)
unnamed: SW1.1 (A), U2.1 (+)
START Kill - not mandatory for sumo: J3.4, J6.1, U3.6 (GPIO18)
START Start: J3.3, J6.2, U3.8 (GPIO14)
US Echo Tx: J5.2, U3.20 (GPIO7)
US Trigger Rx: J5.3, U3.19 (GPIO6-A6)

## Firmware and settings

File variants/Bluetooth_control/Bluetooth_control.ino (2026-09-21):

// Make sure that the following libraries are installed:
// - "NimBLE_Arduino" by h2zero

// Define your robot name below:
#define BLUETOOTH_NAME "MiniSumo Example"

// Define the speeds
#define SPEED_FORWARDS 150
#define SPEED_BACKWARDS 150 
#define SPEED_ROTATE 150

// NO NEED TO TOUCH ANYTHING BELOW THIS LINE
// ----------------------------------------------------------------------------

#include <NimBLEDevice.h>

// Create easier to read names for the pins
enum PinMappings
{
  SIG_KILL,
  MOTOR_IN1,
  MOTOR_IN2,
  MOTOR_IN3,
  MOTOR_IN4,
  _SIZE_LIMIT,
};

// Set up the pin numbers for each sensor, with an easier to read name than just the numbers
static uint8_t const pin[_SIZE_LIMIT] = {
    [SIG_KILL] = 18,
    [MOTOR_IN1] = 0,
    [MOTOR_IN2] = 1,
    [MOTOR_IN3] = 2,
    [MOTOR_IN4] = 3,
};

// Connection status led blinking variables
bool deviceConnected = false;
bool isAdvertising = false;
unsigned long previousMillis = 0;
const unsigned long blinkInterval = 500;
bool ledState = LOW;

// Setup UUID:s which are needed by the BLE
#define SERVICE_UUID        "4fafc201-1fb5-459e-8fcc-c5c9c331914b"
#define CHARACTERISTIC_UUID "beb5483e-36e1-4688-b7f5-ea07361b26a8"

// A simpler function to flash the LED X times
void flash_led(int times){
  for (int i = 0; i < times; i++){
    digitalWrite(LED_BUILTIN, HIGH);
    delay(100);
    digitalWrite(LED_BUILTIN, LOW);
    delay(100);
  }
}

// We want to be informed of when the status of the server changes
class ServerCallbacks : public NimBLEServerCallbacks {
  void onConnect(NimBLEServer* server, NimBLEConnInfo& connInfo) override {
    Serial.println("Client connected");
    deviceConnected = true;
  }

  void onDisconnect(NimBLEServer* server, NimBLEConnInfo& connInfo, int reason) override {
    Serial.print("Client disconnected, reason: ");
    Serial.println(reason);
    deviceConnected = false;

    // Start advertising after a disconnect, otherwise a reboot would be needed
    NimBLEDevice::getAdvertising()->start();
    isAdvertising = true;
  }
};

// We want to be informed when there is a write request to the characteristic
class CommandCallbacks : public NimBLECharacteristicCallbacks {
  void onWrite(
      NimBLECharacteristic* characteristic,
      NimBLEConnInfo& connInfo
  ) override {
    NimBLEAttValue value = characteristic->getValue();
    

    Serial.print("Text: ");
    Serial.println(value);

    switch (static_cast<char>(value[0])) {
      case 'A':
        Serial.println("Forward");
        //flash_led(1);
        forward(SPEED_FORWARDS);
        delay(150);
        stop();
        break;

      case 'B':
        Serial.println("Right");
        //flash_led(2);
        rotateRight(SPEED_FORWARDS);
        delay(150);
        stop();
        break;

      case 'C':
        Serial.println("Backward");
        //flash_led(3);
        backward(SPEED_FORWARDS);
        delay(150);
        stop();
        break;

      case 'D':
        Serial.println("Left");
        //flash_led(4);
        rotateLeft(SPEED_FORWARDS);
        delay(150);
        stop();
        break;

      case 'a':
        Serial.println("Forward");
        //flash_led(1);
        forward(SPEED_FORWARDS);
        delay(100);
        stop();
        break;

      case 'b':
        Serial.println("Right");
        //flash_led(2);
        rotateRight(SPEED_FORWARDS);
        delay(100);
        stop();
        break;

      case 'c':
        Serial.println("Backward");
        //flash_led(3);
        backward(SPEED_FORWARDS);
        delay(100);
        stop();
        break;

      case 'd':
        Serial.println("Left");
        //flash_led(4);
        rotateLeft(SPEED_FORWARDS);
        delay(100);
        stop();
        break;

      case 'E':
        Serial.println("Triangle");
        //flash_led(1);
        stop();
        break;

      case 'F':
        Serial.println("Circle");
        //flash_led(2);
        stop();
        break;

      case 'G':
        Serial.println("Cross");
        //flash_led(3);
        stop();
        break;

      case 'H':
        Serial.println("Square");
        //flash_led(4);
        stop();
        break;

      default:
        Serial.print("Unknown command: ");
        Serial.println(value);
        break;
    }
  }
};

void setup() {
  Serial.begin(115200);
  delay(1000);
  // Set up the LED pin
  pinMode(LED_BUILTIN, OUTPUT);
  // Set up the motor pins
  pinMode(pin[MOTOR_IN1], OUTPUT);
  pinMode(pin[MOTOR_IN2], OUTPUT);
  pinMode(pin[MOTOR_IN3], OUTPUT);
  pinMode(pin[MOTOR_IN4], OUTPUT);


  NimBLEDevice::init(BLUETOOTH_NAME);

  NimBLEServer* server = NimBLEDevice::createServer();
  server->setCallbacks(new ServerCallbacks());

  NimBLEService* service =
      server->createService(SERVICE_UUID);

  NimBLECharacteristic* characteristic =
      service->createCharacteristic(
          CHARACTERISTIC_UUID,
          NIMBLE_PROPERTY::WRITE_NR
      );

  characteristic->setCallbacks(new CommandCallbacks());

  service->start();

  NimBLEAdvertising* advertising =
      NimBLEDevice::getAdvertising();

  advertising->addServiceUUID(SERVICE_UUID);
  advertising->start();
  isAdvertising = true;

  Serial.println("BLE server started");
  Serial.println("Waiting for connection...");
}

void loop() {
    if (!deviceConnected && isAdvertising) {
    unsigned long currentMillis = millis();

    if (currentMillis - previousMillis >= blinkInterval) {
      previousMillis = currentMillis;

      ledState = !ledState;
      digitalWrite(LED_BUILTIN, ledState ? HIGH : LOW);
    }
  }
  delay(10);
}
// Is the stop button pressed?
// Optional for minisumo
void checkStopSignal()
{
//  if (digitalRead(pin[SIG_KILL]) != HIGH)
//  {
//    Serial.println("Got kill signal, stopping..");
//    stop();
//    delay(500);
//  }
}

void forward(int speed)
{
  Serial.println(__func__);
  analogWrite(pin[MOTOR_IN1], speed);
  analogWrite(pin[MOTOR_IN2], 0);
  analogWrite(pin[MOTOR_IN3], 0);
  analogWrite(pin[MOTOR_IN4], speed);
  checkStopSignal();
}

void backward(int speed)
{
  Serial.println(__func__);
  analogWrite(pin[MOTOR_IN1], 0);
  analogWrite(pin[MOTOR_IN2], speed);
  analogWrite(pin[MOTOR_IN3], speed);
  analogWrite(pin[MOTOR_IN4], 0);
  checkStopSignal();
}

void rotateRight(int speed)
{
  Serial.println(__func__);
  analogWrite(pin[MOTOR_IN1], 0);
  analogWrite(pin[MOTOR_IN2], speed);
  analogWrite(pin[MOTOR_IN3], 0);
  analogWrite(pin[MOTOR_IN4], speed);
  checkStopSignal();
}

void rotateLeft(int speed)
{
  Serial.println(__func__);
  analogWrite(pin[MOTOR_IN1], speed);
  analogWrite(pin[MOTOR_IN2], 0);
  analogWrite(pin[MOTOR_IN3], speed);
  analogWrite(pin[MOTOR_IN4], 0);
  checkStopSignal();
}

void stop()
{
  Serial.println(__func__);
  analogWrite(pin[MOTOR_IN1], 0);
  analogWrite(pin[MOTOR_IN2], 0);
  analogWrite(pin[MOTOR_IN3], 0);
  analogWrite(pin[MOTOR_IN4], 0);
}

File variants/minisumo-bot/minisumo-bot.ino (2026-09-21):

// Make sure that the following libraries are installed:
// - "HCSR04" by Martin Sosic

// Define the speeds
#define SPEED_FORWARDS 150
#define SPEED_BACKWARDS 150 
#define SPEED_ROTATE 150

// NO NEED TO TOUCH ANYTHING BELOW THIS LINE
// ----------------------------------------------------------------------------

#include <HCSR04.h>

// Create easier to read names for the pins
enum PinMappings
{
  SIG_START,
  SIG_KILL,
  MOTOR_IN1,
  MOTOR_IN2,
  MOTOR_IN3,
  MOTOR_IN4,
  SENSOR_IR_FRONT,
  SENSOR_IR_BACK,
  SENSOR_SND_TRIG,
  SENSOR_SND_ECHO,
  _SIZE_LIMIT,
};

// Set up the pin numbers for each sensor, with an easier to read name than just the numbers
static uint8_t const pin[_SIZE_LIMIT] = {
    [SIG_START] = 14,
    [SIG_KILL] = 18,
    [MOTOR_IN1] = 0,
    [MOTOR_IN2] = 1,
    [MOTOR_IN3] = 2,
    [MOTOR_IN4] = 3,
    [SENSOR_IR_FRONT] = 4,
    [SENSOR_IR_BACK] = 5,
    [SENSOR_SND_TRIG] = 6,
    [SENSOR_SND_ECHO] = 7,
};

// Distance in cm 
UltraSonicDistanceSensor hcsr04(pin[SENSOR_SND_TRIG], pin[SENSOR_SND_ECHO]);

void setup()
{
  Serial.begin(115200);
  // A delay since otherwise the serial output may not show up
  delay(1000);
  // Set up the motor pins
  pinMode(pin[MOTOR_IN1], OUTPUT);
  pinMode(pin[MOTOR_IN2], OUTPUT);
  pinMode(pin[MOTOR_IN3], OUTPUT);
  pinMode(pin[MOTOR_IN4], OUTPUT);

  //waitStartSignal();
  
  Serial.println("Started measuring");
}

void loop()
{
  float distanceCm = hcsr04.measureDistanceCm();

  // Rotate left to find opponent
  rotateLeft(SPEED_ROTATE);

  // If opponent found
  while (distanceCm < 40 && distanceCm > 0)
  {
    // IR value = 0 if senses border
    int frontIR = digitalRead(pin[SENSOR_IR_FRONT]);
    Serial.print("Front IR: ");
    Serial.println(frontIR);
    // IR value = 0 if senses border 
    int backIR = digitalRead(pin[SENSOR_IR_BACK]);
    Serial.print("Back IR: ");
    Serial.println(backIR);
    
    if (checkBorder()) {
      // Border is present, drive away from it and then exit loop
      break;
    }
    // Drive towards opponent
    forward(SPEED_FORWARDS); 
    // Update the measurement, is the opponent gone?
    distanceCm = hcsr04.measureDistanceCm();
  }
  // Check so not fall off
  checkBorder();
 
  Serial.println(distanceCm);
  delay(150);
}

void waitStartSignal()
{
  Serial.println(__func__);
  while (digitalRead(pin[SIG_START]) != HIGH)
  {
    Serial.println("Waiting for start signal");
  }
}

// Is the stop button pressed?
// Optional for minisumo
void checkStopSignal()
{
//  if (digitalRead(pin[SIG_KILL]) != HIGH)
//  {
//    Serial.println("Got kill signal, stopping..");
//    stop();
//    delay(500);
//  }
}

// Check so not fall off
// Returns true if border is either in front or back of us.
// Returns false if border is not present
bool checkBorder()
{
  // IR value = 0 if senses border
  int frontIR = digitalRead(pin[SENSOR_IR_FRONT]);
  int backIR = digitalRead(pin[SENSOR_IR_BACK]);
  // Check if edge is in front of us 
  if (frontIR == 0)
  {
    backward(SPEED_BACKWARDS);
    delay(500);
    return true;
  }

  // Check if edge is behind us
  if (backIR == 0)
  {
    forward(SPEED_FORWARDS);
    delay(500);
    return true;
  }

  return false;
}

void forward(int speed)
{
  Serial.println(__func__);
  analogWrite(pin[MOTOR_IN1], speed);
  analogWrite(pin[MOTOR_IN2], 0);
  analogWrite(pin[MOTOR_IN3], 0);
  analogWrite(pin[MOTOR_IN4], speed);
  checkStopSignal();
}

void backward(int speed)
{
  Serial.println(__func__);
  analogWrite(pin[MOTOR_IN1], 0);
  analogWrite(pin[MOTOR_IN2], speed);
  analogWrite(pin[MOTOR_IN3], speed);
  analogWrite(pin[MOTOR_IN4], 0);
  checkStopSignal();
}

void rotateLeft(int speed)
{
  Serial.println(__func__);
  analogWrite(pin[MOTOR_IN1], 0);
  analogWrite(pin[MOTOR_IN2], speed);
  analogWrite(pin[MOTOR_IN3], 0);
  analogWrite(pin[MOTOR_IN4], speed);
  checkStopSignal();
}

void rotateRight(int speed)
{
  Serial.println(__func__);
  analogWrite(pin[MOTOR_IN1], speed);
  analogWrite(pin[MOTOR_IN2], 0);
  analogWrite(pin[MOTOR_IN3], speed);
  analogWrite(pin[MOTOR_IN4], 0);
  checkStopSignal();
}

void stop()
{
  Serial.println(__func__);
  analogWrite(pin[MOTOR_IN1], 0);
  analogWrite(pin[MOTOR_IN2], 0);
  analogWrite(pin[MOTOR_IN3], 0);
  analogWrite(pin[MOTOR_IN4], 0);
}

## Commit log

2026-09-03 pcb - initial into repository .. changed after 260901 along with general cleanup also mainly included:
    traces moved for ir as c6 was not cooperating with these connected
    smaller switch!
    aligned bottom connectors to allow for single header connection
    created readme.md!!
    [minisumo_plusplus_2027 - Copy.kicad_pcb, minisumo_plusplus_2027.kicad_pcb, minisumo_plusplus_2027.kicad_sch]
2026-09-03 pcb updates to clean up a abit, drc was quite ok!
    folders & inspiration images of lego and death racer robots
    [minisumo_plusplus_2027.kicad_pcb]
2026-09-04 cleaned up pcb more and fixed / prepared for the eventual migration to the 10x10 inkl extra stripboard!
    [minisumo_plusplus_2027.kicad_pcb]
2026-09-04 pcb kicad fixed zoom issue! (extranous bits somewhere..)
    [minisumo_plusplus_2027.kicad_pcb]
2026-09-07 small fix and test of motor driver without silk overflow
2026-09-07 pcb fixing silkscreens and cleanups based primarily on esp32 c6 improved batt pads and middle board pin positions based on images
    [minisumo_plusplus_2027.kicad_pcb]
2026-09-07 Fix left and right
    [Bluetooth_control.ino, sumobot.ino]
2026-09-07 pcb - 1x10 for ir front/back and ultrasonic instead of 2x 1x3 + 1x4 && also included a 6x fab board example of latest board
    [minisumo_plusplus_2027.kicad_pcb, minisumo_plusplus_2027.kicad_sch]
2026-09-08 pcb - updated esp32 c6 footprint to match better && fixed traces based on some potential ANT issues leading to these improvements
    [minisumo_plusplus_2027.kicad_pcb]
2026-09-08 pcb refreshed ground plane
    [minisumo_plusplus_2027.kicad_pcb]
2026-09-13 pcb latest w/ clean cutout and gerber (6x in 10x10cm)
    [minisumo_plusplus_2027.kicad_pcb]
2026-09-14 pcb - mounting holes added during meeting && 3d step files
    [CR123.step, L298N_mini.stp, LM2596-HW-411.stp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]
2026-09-14 pcb now with 2a buck boost MT3608, updated footprints incl motor driver @2.54 pins int1-4, and c6 && 3d with updated buck boost along with pcb!
    [MT3608 v3.step, main_assy_260914a.FCStd, minisumo_plusplus_2027-260914a pre design review.step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]
2026-09-14 3d updates incl moving assy file and adding xh 2.54 model from grabcad
    [XH_top_entry+housing-10pin_2.54mm.FCStd, XH_top_entry+housing.FCStd, main_assy_260914a.FCStd]
2026-09-15 pcb - fixed traces incl around antenna a gnd strip outside keepout on A side with stitching vias and no gnd plane on b side acc to espressif instructions
    [minisumo_plusplus_2027.kicad_pcb]
2026-09-15 3d - pcb step added bat contacts to pcb and incl motors and played a bit with trying to find a workable orientation of pcb/motors within the envelope 10x10cm, not happy with it at the moment..
    [Bat neg.STEP, CR123.step, TT Motor Dual Shaft.step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]
2026-09-15 pcb .. fixed a 3v3 trace near battery cut
    [minisumo_plusplus_2027.kicad_pcb]
2026-09-16 pcb - updated footprints w 3d and fixed broken traces && 3d - redid assemblies they were a bit of a mess.
    [CR123.step, MT3608 Converter.STEP, PCB_assy.FCStd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]
2026-09-16 ORDER - as ordered for prototyper! pcb schematic and layout touched up just before sending. 7.36eur 12-16d shipping estimate was to be produced by the 20th (sunday) so long as passes review.
    [PCB_assy.FCStd, main_assy.FCStd, minisumo_plusplus_2027-260916a.step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]
2026-09-20 3d - IR and Ultrasonic sensors added to main_assy
    [HC-SR04_UltraSonic Sensor.step, IR_LM393_pin.stp, IR_sensor.FCStd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]
2026-09-20 3d wheel(s)!
    [main_assy.FCStd, wheel.FCStd]
2026-09-21 3d updated main_assy & pcb w pcb with actual holes from kicad (except oblong by batt as this is what caused edge cuts to fail) && added line follower assy a start on a 3d poc
    [PCB_assy.FCStd, linefollower-main_assy.FCStd, main_assy.FCStd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]
2026-09-22 Add old chassis
    [Old_Sumobot.v7.3mf]
2026-09-27 Remove tag push filter from workflow
